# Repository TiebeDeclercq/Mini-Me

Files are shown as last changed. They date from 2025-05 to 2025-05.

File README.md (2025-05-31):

# Mini-Me

An animatronic robot that naturally mimics human movements with multiple control interfaces (UDP & Bottango)

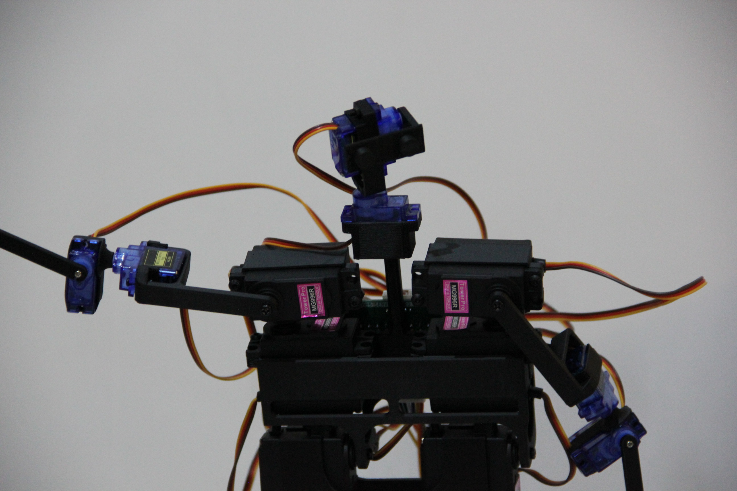
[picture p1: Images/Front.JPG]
Mini-Me


## Hardware Overview

The system uses a dual-microcontroller architecture:
- **STM32G030C8T:** Hardware control and servo management
- **ESP32-WROOM-32E-N8:** WiFi communication and external interfaces
- **19 servo motors** controlled via 2x PCA9685 PWM drivers
- **Custom PCBs** for main control and servo distribution
- **12V power supply** with buck converter and current monitoring

## Assembly Instructions

**3D Printed Parts**
The mechanical design consists of 22 different parts, all designed in Fusion 360 for the Bambu Lab P1S printer. Print all STL files from the `/Printfiles/` directory.

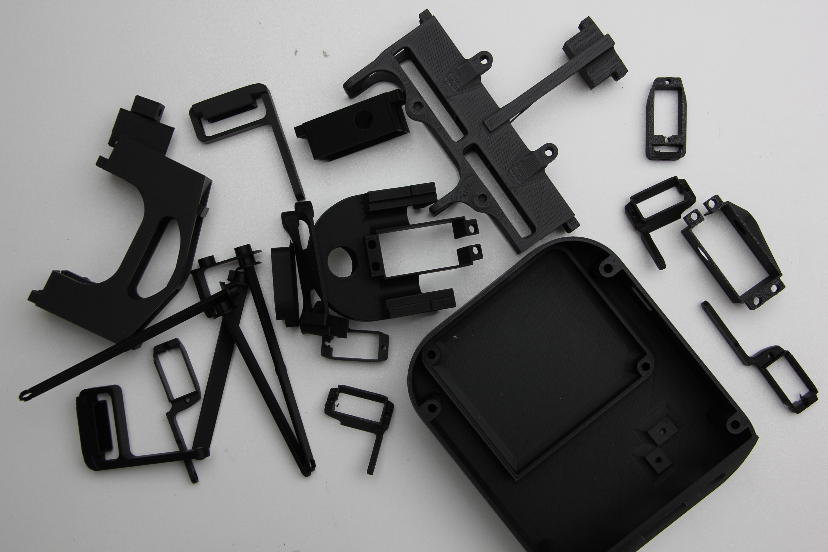
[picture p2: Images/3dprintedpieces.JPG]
3D Printed Pieces


**Magnet Integration**
During printing, pause the G-code at specified layers to insert magnets into the head, arms, and legs. This allows easy attachment of accessories and face variations.

**PCB Assembly**
1. Order PCBs using Gerber files in `/Pcb's/`
2. Solder components according to the provided BOMs
3. Main board includes ESP32, STM32, power management, and interfaces
4. Servo boards use JST connectors for secure servo connections

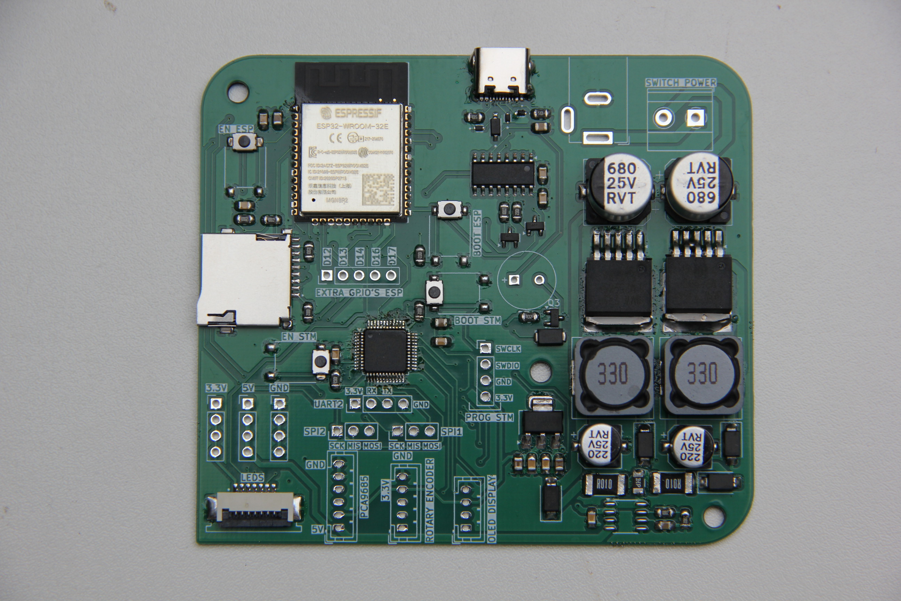
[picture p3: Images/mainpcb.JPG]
Main pcb

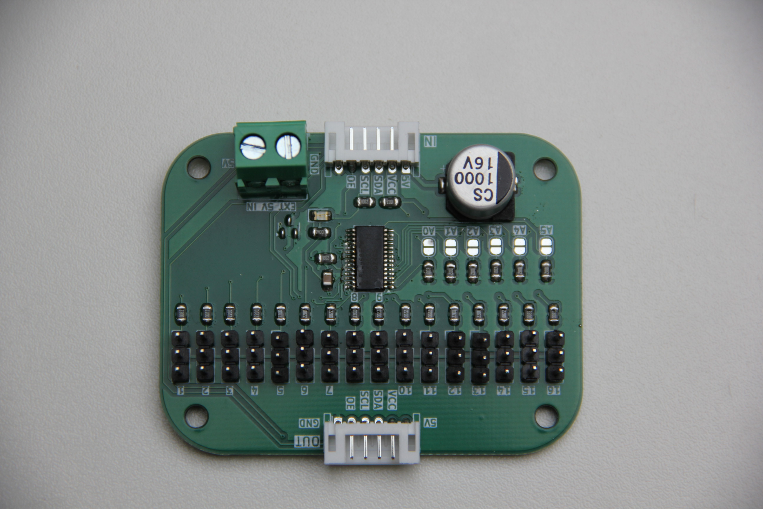
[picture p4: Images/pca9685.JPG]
Servo board pcb


**Final Assembly**
1. Install PCBs in the base/foot assembly
2. Connect servo boards via ribbon cables
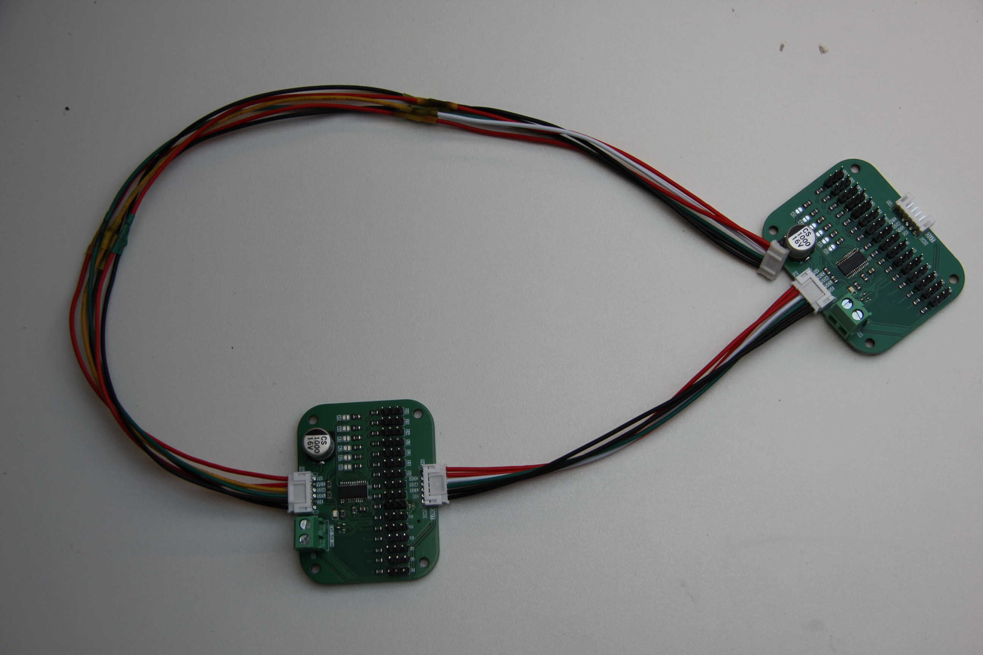
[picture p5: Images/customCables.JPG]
Custom Cables

3. Mount OLED display and rotary encoder in base
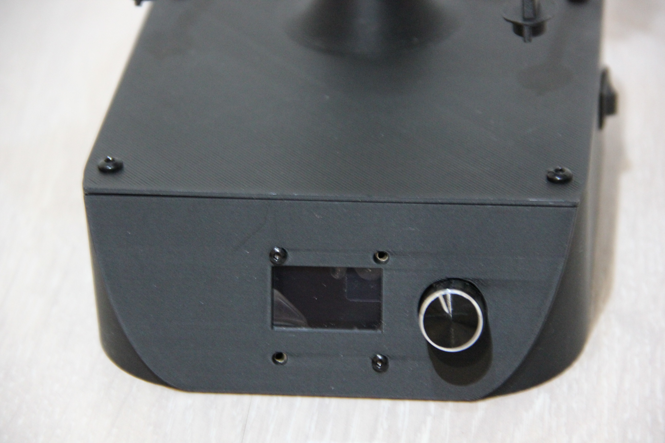
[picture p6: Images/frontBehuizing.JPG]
Base

4. Assemble skeleton parts with integrated magnets
5. Connect all servos to appropriate servo board positions

## Software

**Firmware**
- **ESP32:** Programmed with PlatformIO (C++)
- **STM32:** Programmed with STM32CubeIDE

**Control Applications**
- **Mobile App (Flutter):** Smartphone-based control interface via UDP
- **Bottango Integration:** Professional animation software compatibility

**Network Control**
The robot accepts UDP commands in JSON format:
```json
{"servo": 1, "angle": 90}
{"servos": [{"id": 1, "angle": 90}, {"id": 2, "angle": 45}]}
```

## Getting Started

1. **3D Print** all parts from `/Printfiles/`
2. **Order and assemble** PCBs using provided files and BOMs
3. **Flash firmware** from `/Firmware/Mini-Me-DevBoard/` and `/Firmware/MINI-ME-ESP32/`
4. **Install control software** of choice from `/Software/`
5. **Connect to WiFi** and start controlling via UDP or applications

**Project Report:** [Complete documentation available](docs/Mini-Me-Report.pdf)

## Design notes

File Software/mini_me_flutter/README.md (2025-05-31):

# mini_me

A new Flutter project.

## Getting Started

This project is a starting point for a Flutter application.

A few resources to get you started if this is your first Flutter project:

- [Lab: Write your first Flutter app](https://docs.flutter.dev/get-started/codelab)
- [Cookbook: Useful Flutter samples](https://docs.flutter.dev/cookbook)

For help getting started with Flutter development, view the
[online documentation](https://docs.flutter.dev/), which offers tutorials,
samples, guidance on mobile development, and a full API reference.

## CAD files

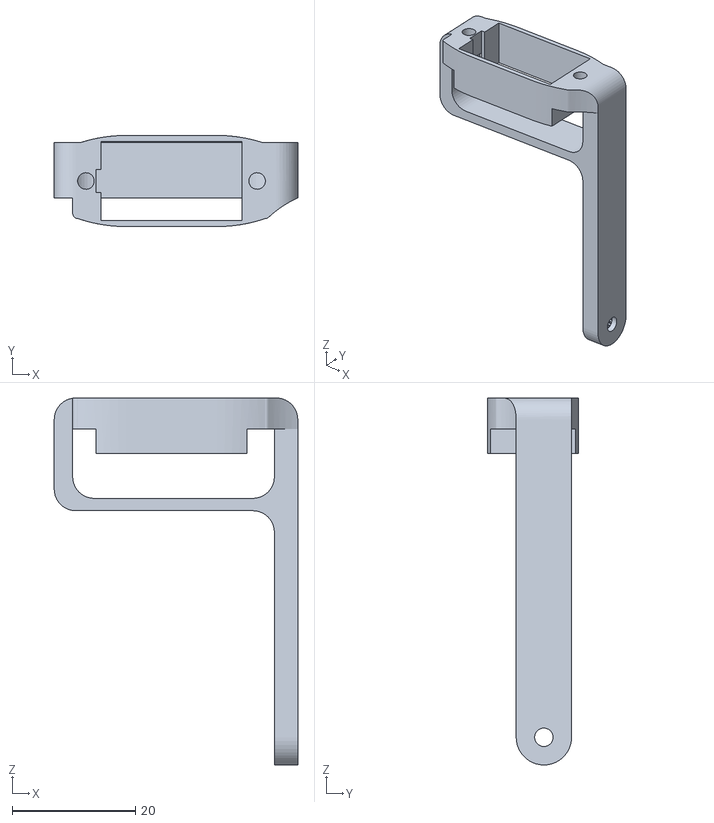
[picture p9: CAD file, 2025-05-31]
Printfiles/Lunderarm.stl
39.6 x 14.8 x 59.6

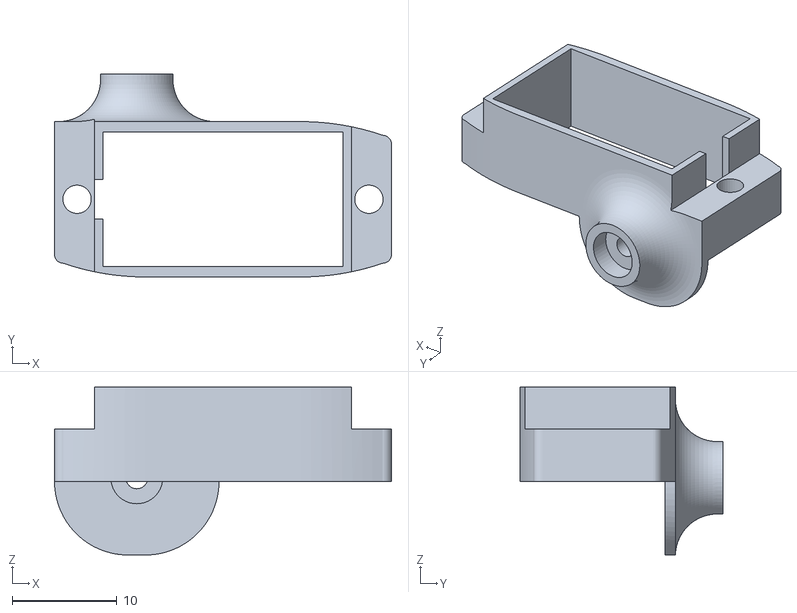
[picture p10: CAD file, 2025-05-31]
Printfiles/RupperArm.stl
32.1 x 19.3 x 16.0

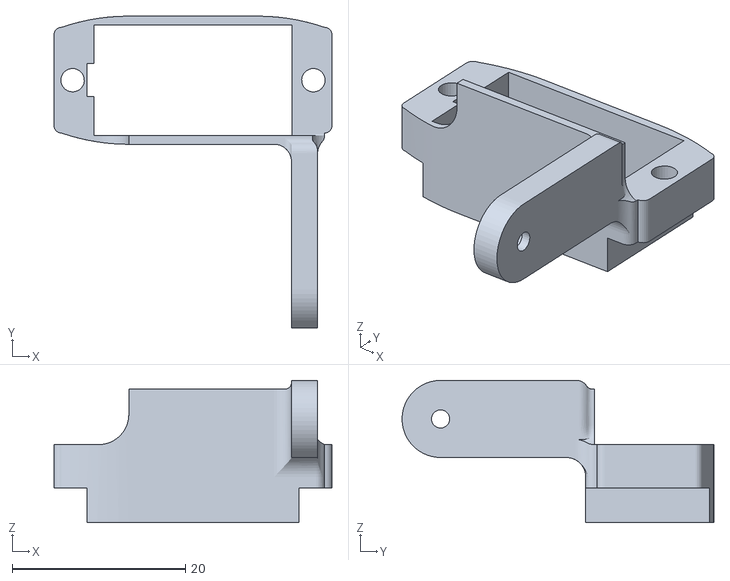
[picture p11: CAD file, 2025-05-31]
Printfiles/lUpperLeg.stl
32.1 x 36.0 x 16.4

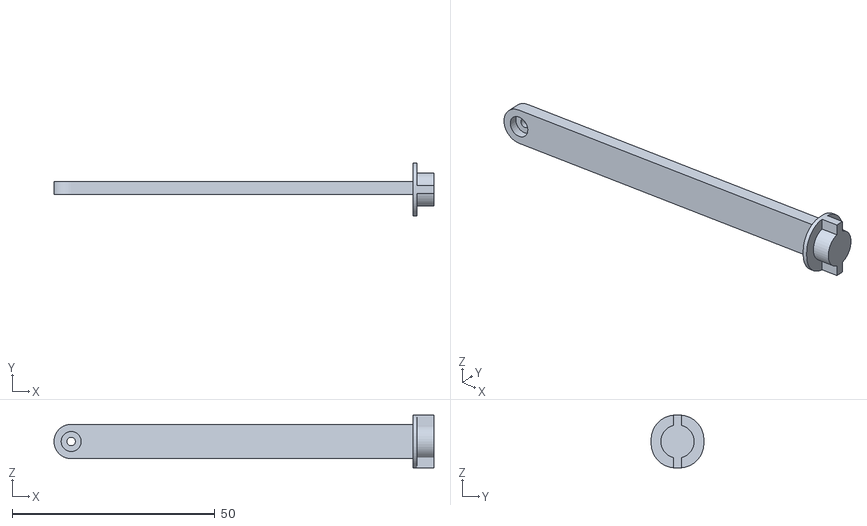
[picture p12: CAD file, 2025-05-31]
Printfiles/rLeg.stl
93.7 x 13.0 x 13.0

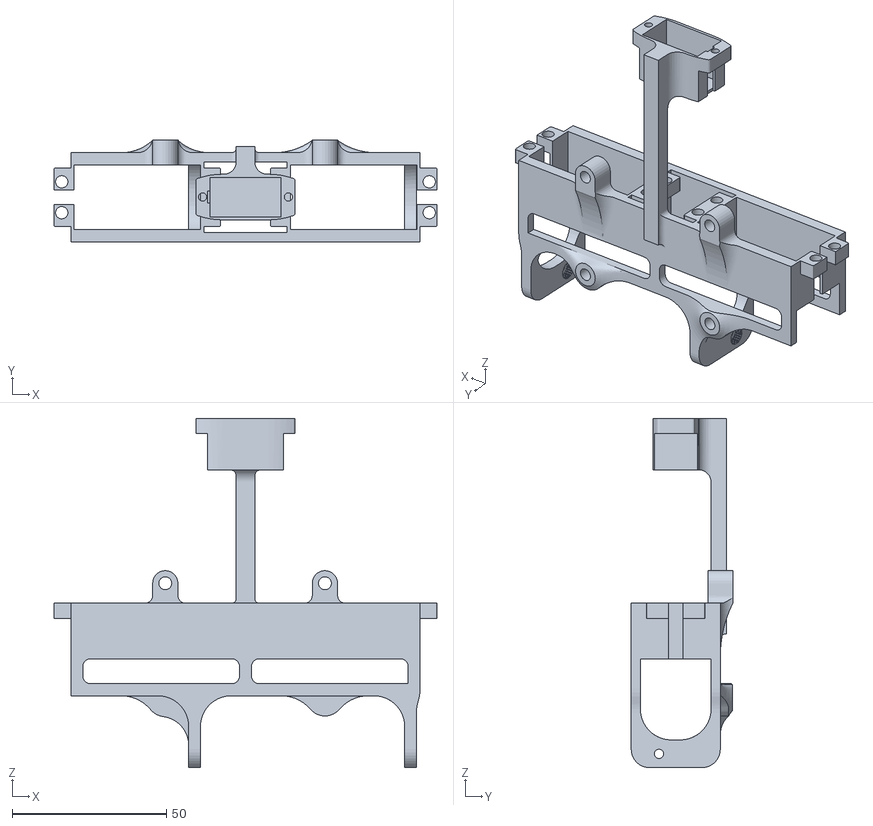
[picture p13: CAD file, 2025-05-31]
Printfiles/upperBody.stl
124.1 x 33.0 x 113.2

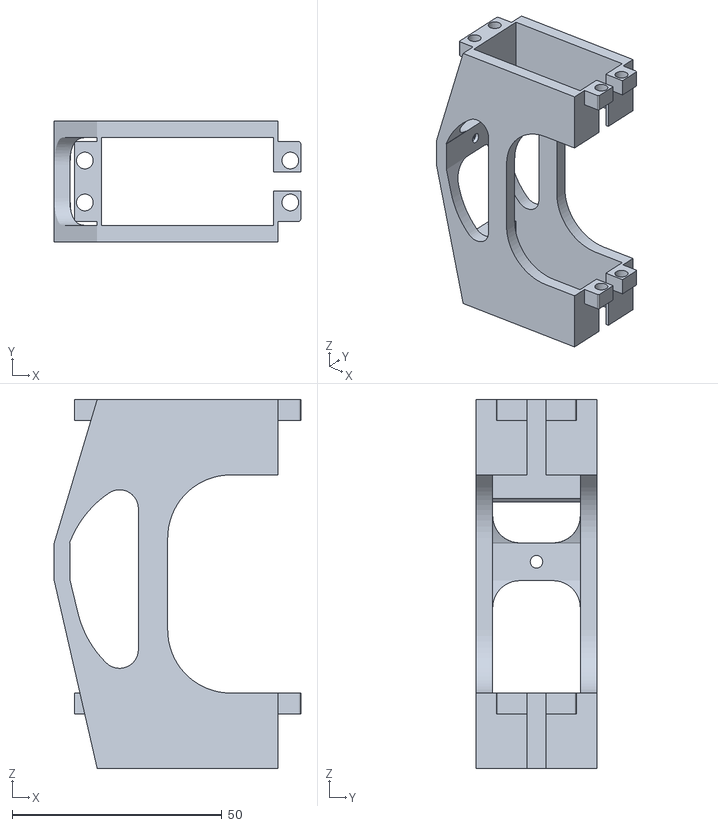
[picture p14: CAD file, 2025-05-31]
Printfiles/tummy.stl
58.8 x 28.9 x 88.0

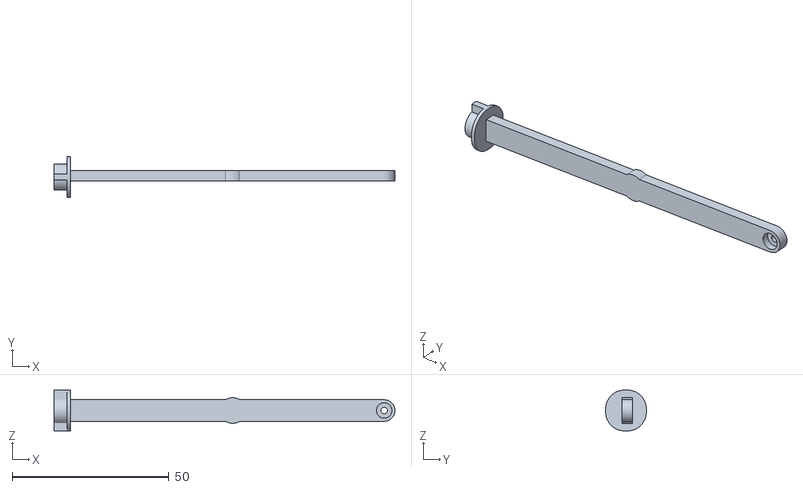
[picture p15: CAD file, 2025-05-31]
Printfiles/Larm.stl
108.6 x 13.0 x 13.0

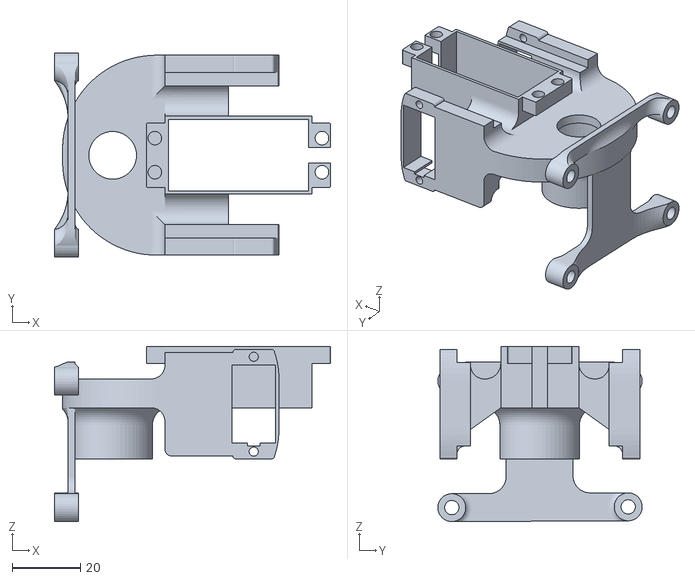
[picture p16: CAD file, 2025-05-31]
Printfiles/poop.stl
80.9 x 59.9 x 51.4

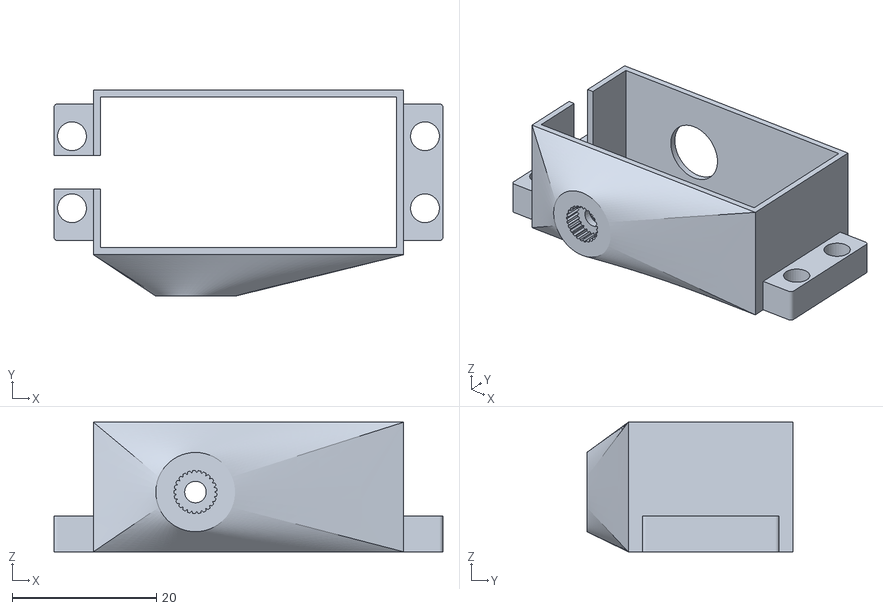
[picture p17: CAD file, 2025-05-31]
Printfiles/Relbow.stl
54.0 x 28.7 x 18.0

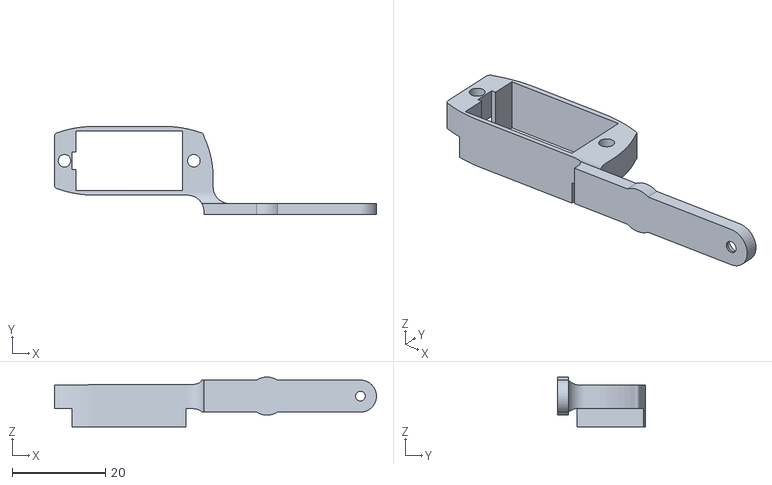
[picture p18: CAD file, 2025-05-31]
Printfiles/lMiddleLeg.stl
69.2 x 19.0 x 10.7

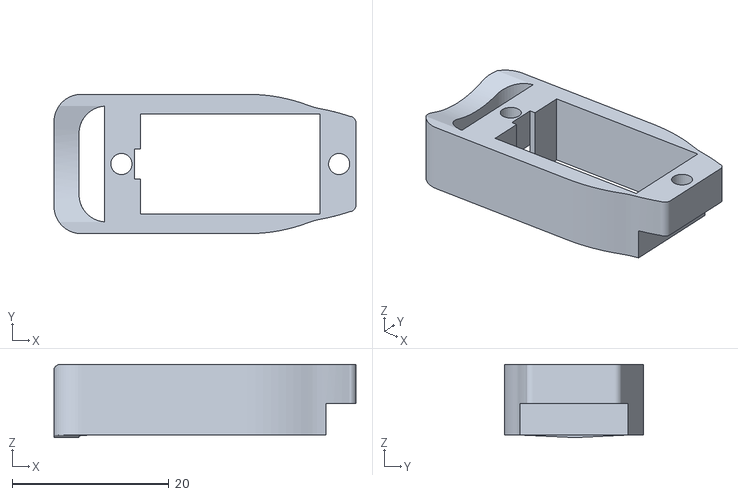
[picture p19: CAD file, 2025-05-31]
Printfiles/headY.stl
38.6 x 17.8 x 9.35

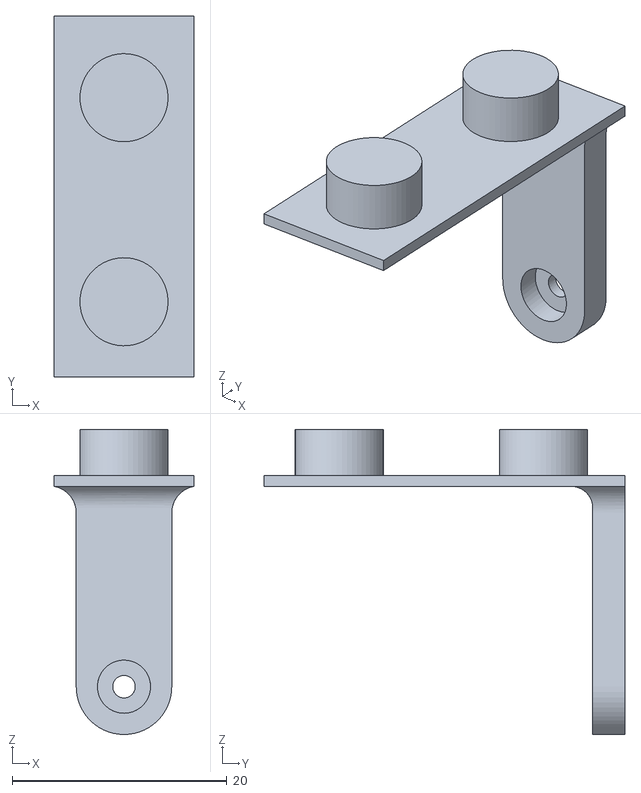
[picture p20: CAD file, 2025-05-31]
Printfiles/headX.stl
13.0 x 33.6 x 28.4

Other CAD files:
Printfiles/Lelbow.stl
Printfiles/Rlowerarm.stl
Printfiles/LYMOVEMENT.stl
Printfiles/rLowerLeg.stl
Printfiles/buttonStand.stl
Printfiles/enclosure.stl
Printfiles/lid.stl
Printfiles/rUpperLeg.stl

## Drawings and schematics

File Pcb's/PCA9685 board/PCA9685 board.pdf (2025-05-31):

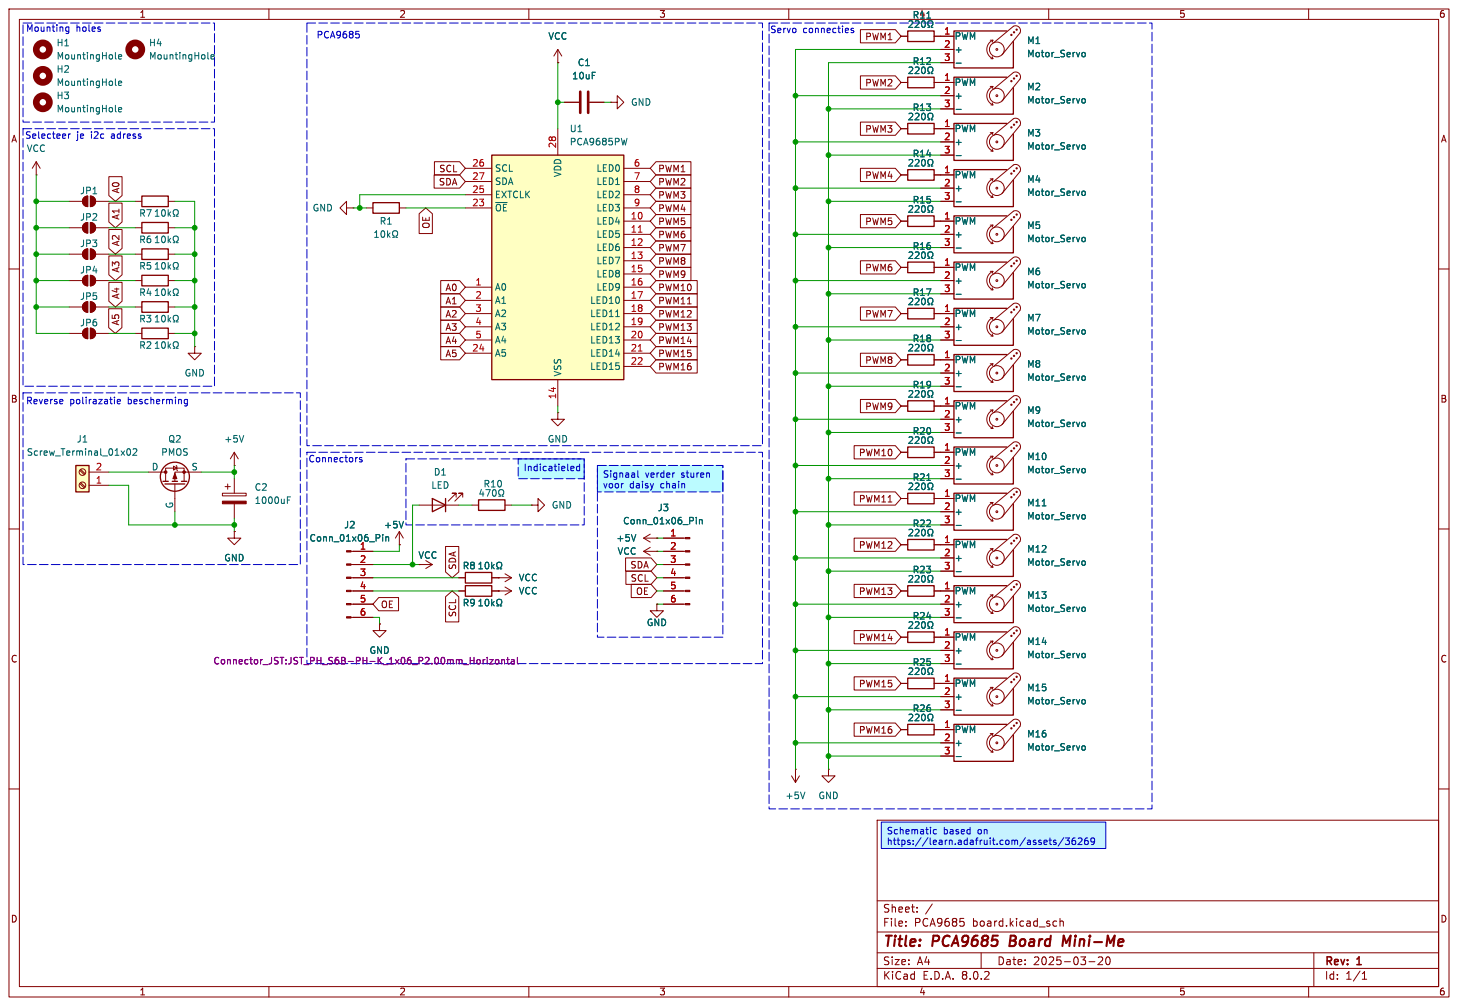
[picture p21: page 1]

https://learn.adafruit.com/assets/36269

Id: 1/1 Title: PCA9685 Board Mini-Me

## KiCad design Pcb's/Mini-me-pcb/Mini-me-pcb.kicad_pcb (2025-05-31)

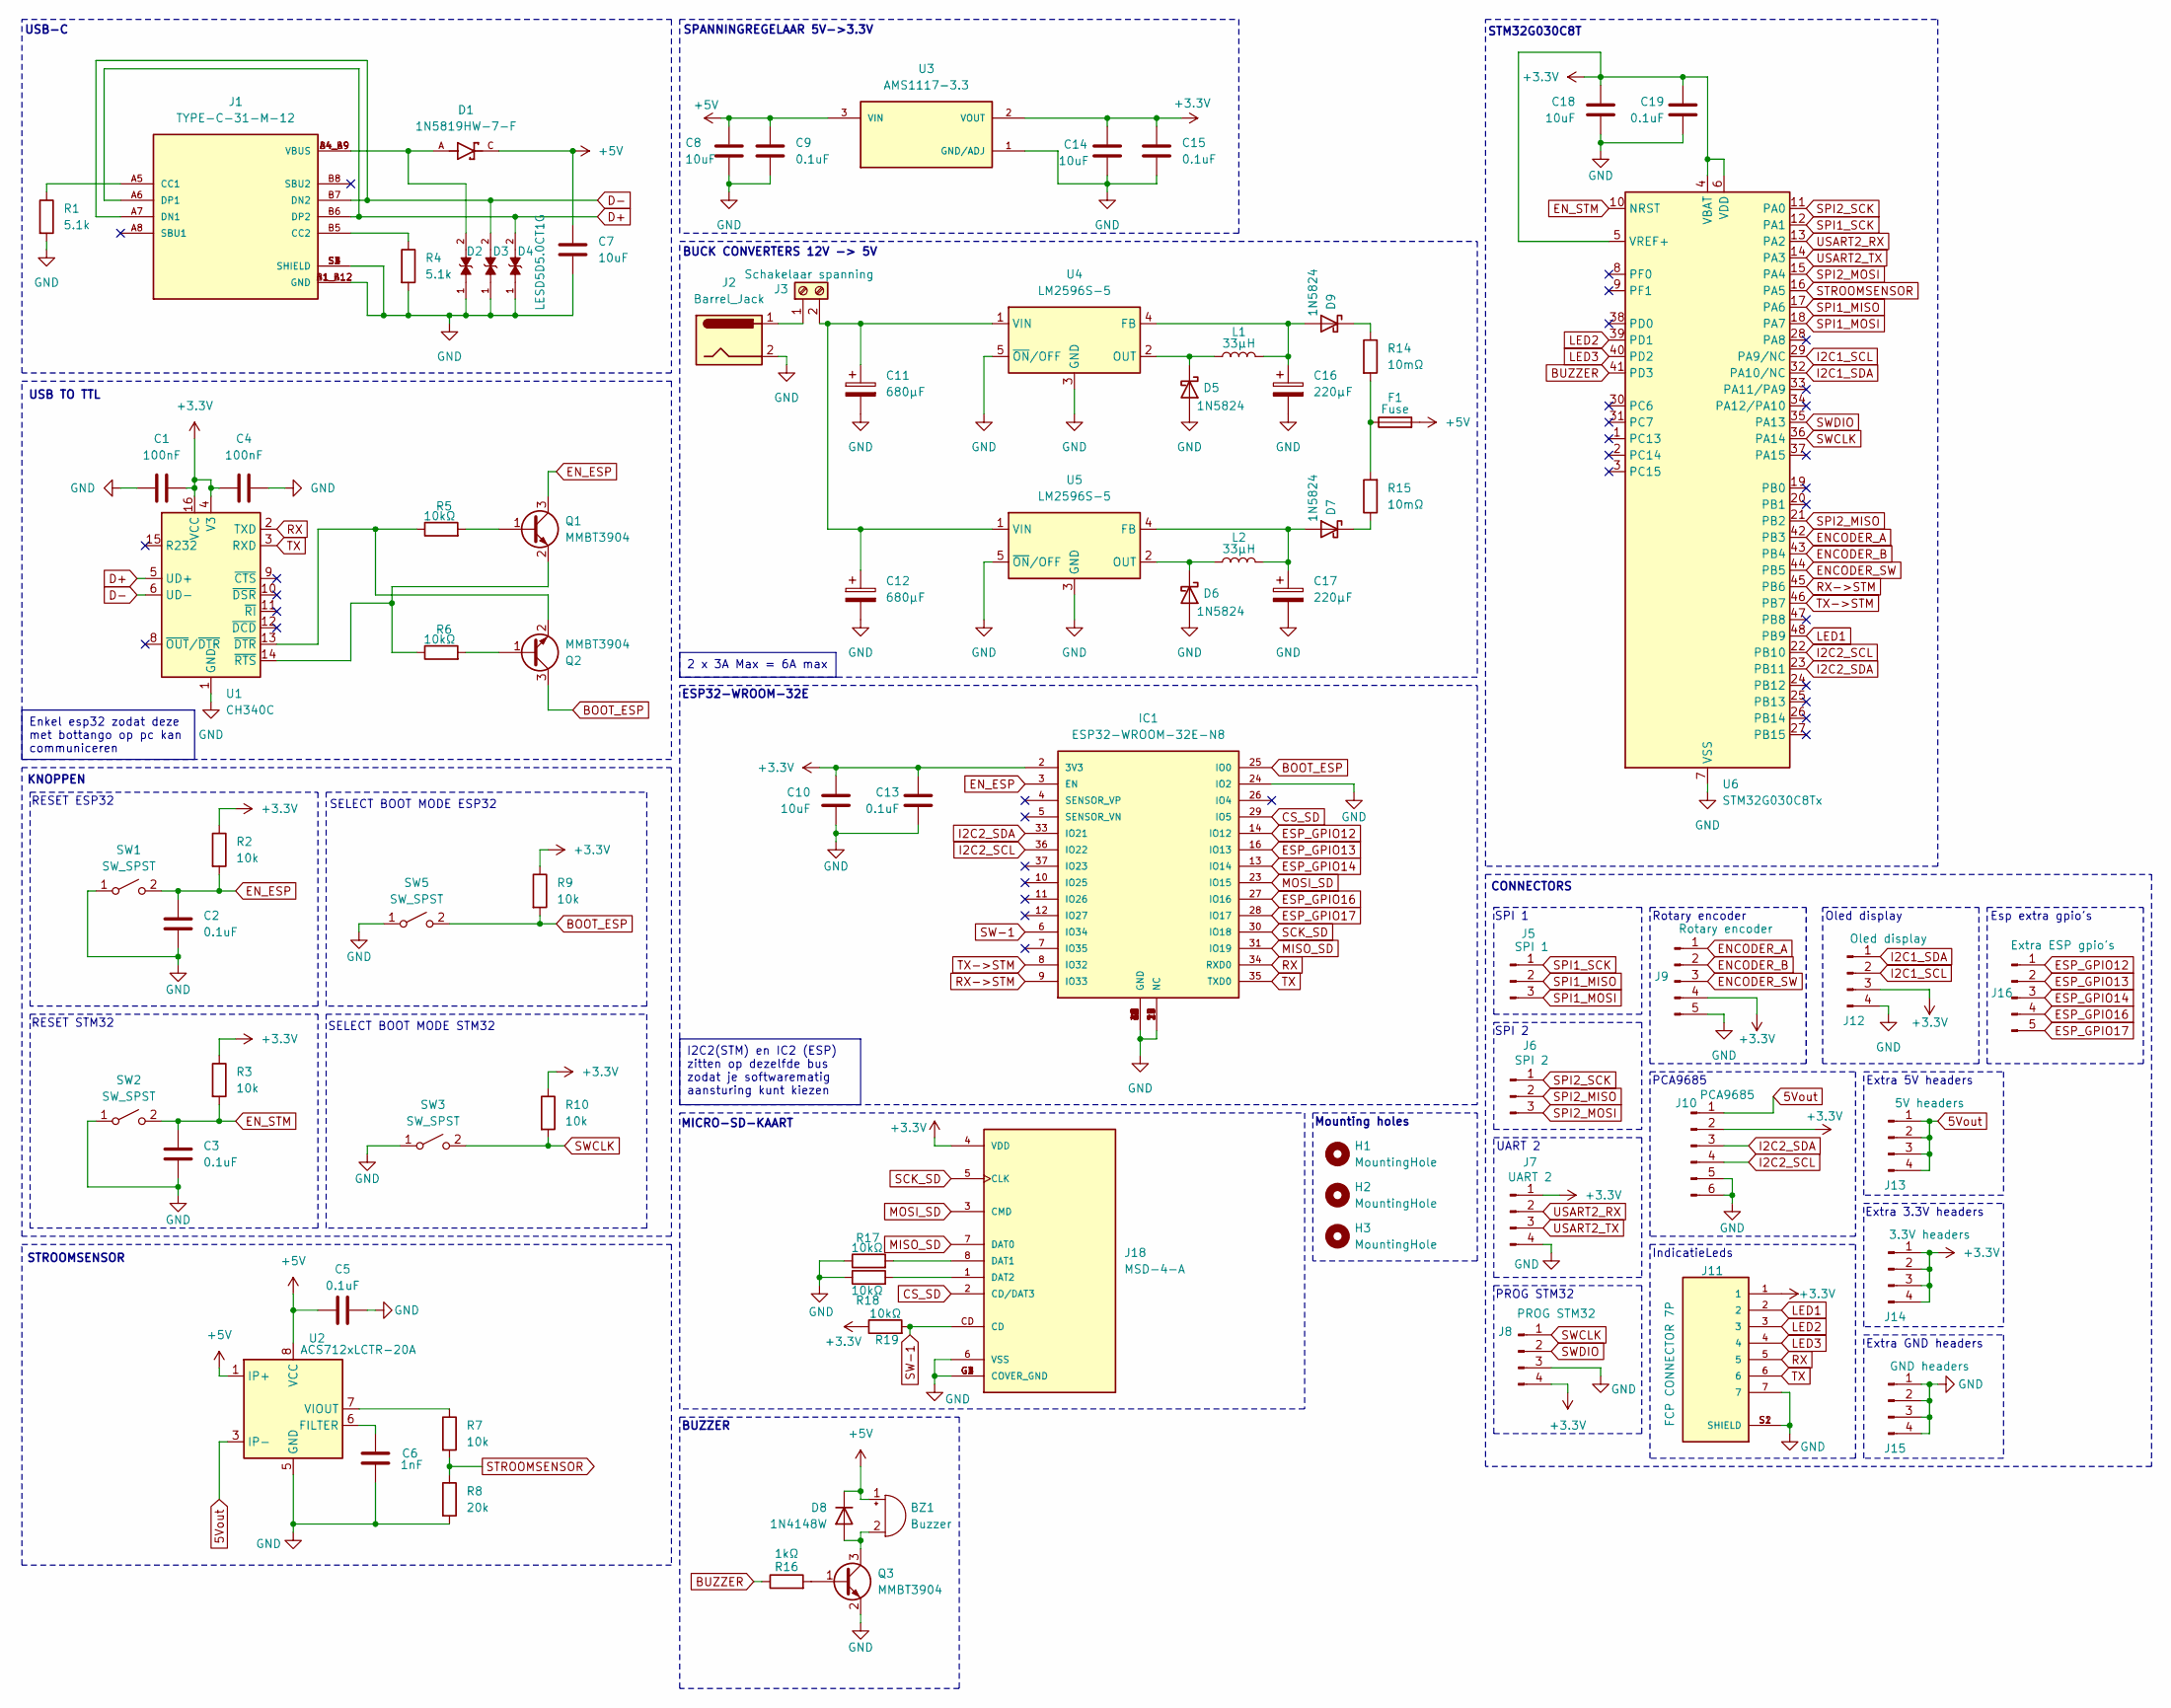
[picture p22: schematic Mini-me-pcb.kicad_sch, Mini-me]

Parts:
BZ1: Buzzer; MagneticBuzzer_PUI_AT-0927-TT-6-R
C1, C4: 100nF; C_0805_2012Metric_Pad1.18x1.45mm_HandSolder
C2, C3, C5, C9, C13, C15, C19: 0.1uF; C_0805_2012Metric_Pad1.18x1.45mm_HandSolder
C6: 1nF; C_0805_2012Metric_Pad1.18x1.45mm_HandSolder
C7, C8, C10, C14, C18: 10uF; C_0805_2012Metric_Pad1.18x1.45mm_HandSolder
C11, C12: 680µF; CP_Elec_10x10
C16, C17: 220µF; CP_Elec_6.3x7.7
D1: 1N5819HW-7-F; SOD3715X145N; PARTREV 18-2
D2, D3, D4: LESD5D5.0CT1G; TVS_LESD5D5.0CT1G; PARTREV O
D5, D6, D7, D9: 1N5824; D_SMA
D8: 1N4148W; D_SOD-123
F1: Fuse; Fuse_1206_3216Metric
H1, H2, H3: MountingHole; MountingHole_3.2mm_M3
IC1: ESP32-WROOM-32E-N8; ESP32WROOM32EN8; MOUSER_PART_NUMBER 356-ESP32WRM32E164PH
J1: TYPE-C-31-M-12; HRO_TYPE-C-31-M-12; PARTREV 2020.12.08
J2: Barrel_Jack; BarrelJack_GCT_DCJ200-10-A_Horizontal
J3: Schakelaar spanning; TerminalBlock_Phoenix_MKDS-1,5-2-5.08_1x02_P5.08mm_Horizont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
J5: SPI 1; PinHeader_1x03_P2.54mm_Vertical
J6: SPI 2; PinHeader_1x03_P2.54mm_Vertical
J7: UART 2; PinHeader_1x04_P2.54mm_Vertical
J8: PROG STM32; PinHeader_1x04_P2.54mm_Vertical
J9: Rotary encoder; JST_PH_B5B-PH-K_1x05_P2.00mm_Vertical
J10: PCA9685; JST_PH_B6B-PH-K_1x06_P2.00mm_Vertical
J11: FCP CONNECTOR 7P; FCP7P; PARTREV A4
J12: Oled display; JST_PH_B4B-PH-K_1x04_P2.00mm_Vertical
J13: 5V headers; PinHeader_1x04_P2.54mm_Vertical
J14: 3.3V headers; PinHeader_1x04_P2.54mm_Vertical
J15: GND headers; PinHeader_1x04_P2.54mm_Vertical
J16: Extra ESP gpio's; PinHeader_1x05_P2.54mm_Vertical
J18: MSD-4-A; CUI_MSD-4-A; PARTREV 1.0
L1, L2: 33µH; L_SXN_SMDRI125
Q1, Q2, Q3: MMBT3904; SOT-23
R1, R4: 5.1k; R_0805_2012Metric_Pad1.20x1.40mm_HandSolder
R2, R3, R7, R9, R10: 10k; R_0805_2012Metric_Pad1.20x1.40mm_HandSolder
R5, R6, R17, R18, R19: 10kΩ; R_0805_2012Metric_Pad1.20x1.40mm_HandSolder
R8: 20k; R_0805_2012Metric_Pad1.20x1.40mm_HandSolder
R14, R15: 10mΩ; R_2512_6332Metric
R16: 1kΩ; R_0805_2012Metric_Pad1.20x1.40mm_HandSolder
SW1, SW2, SW3, SW5: SW_SPST; SW_SPST_PTS645
U1: CH340C; SOIC-16_3.9x9.9mm_P1.27mm
U2: ACS712xLCTR-20A; SOIC-8_3.9x4.9mm_P1.27mm
U3: AMS1117-3.3; SOT-223; PARTREV N/A
U4, U5: LM2596S-5; TO-263-5_TabPin3
U6: STM32G030C8Tx; LQFP-48_7x7mm_P0.5mm

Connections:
5Vout: J10.1, J13.1, J13.2, J13.3, J13.4, U2.3 (IP-), U2.4 (IP-)
+3.3V: C1.2, C4.1, C10.1, C13.1, C14.1, C15.1, C18.1, C19.1, IC1.2 (3V3), J7.1, J8.4, J9.4, J10.2, J11.1, J12.3, J14.1, J14.2, J14.3, J14.4, J18.4 (VDD), R2.1, R3.1, R9.1, R10.1, R19.1, U1.4 (V3), U1.16 (VCC), U3.2 (VOUT), U6.4 (VBAT), U6.5 (VREF+), U6.6 (VDD)
+5V: BZ1.1 (-), C5.1, C7.1, C8.1, C9.1, D1.C, D8.1 (K), F1.2, U2.1 (IP+), U2.2 (IP+), U2.8 (VCC), U3.3 (VIN)
BOOT_ESP: IC1.25 (IO0), Q2.3 (C), R9.2, SW5.2 (B)
BUZZER: R16.1, U6.41 (PD3)
CS_SD: IC1.29 (IO5), J18.2 (CD/DAT3)
D+: D4.2, J1.A6 (DP1), J1.B6 (DP2), U1.5 (UD+)
D-: D3.2, J1.A7 (DN1), J1.B7 (DN2), U1.6 (UD-)
ENCODER_A: J9.1, U6.42 (PB3)
ENCODER_B: J9.2, U6.43 (PB4)
ENCODER_SW: J9.3, U6.44 (PB5)
EN_ESP: C2.1, IC1.3 (EN), Q1.3 (C), R2.2, SW1.2 (B)
EN_STM: C3.1, R3.2, SW2.2 (B), U6.10 (NRST)
ESP_GPIO12: IC1.14 (IO12), J16.1
ESP_GPIO13: IC1.16 (IO13), J16.2
ESP_GPIO14: IC1.13 (IO14), J16.3
ESP_GPIO16: IC1.27 (IO16), J16.4
ESP_GPIO17: IC1.28 (IO17), J16.5
GND: C1.1, C2.2, C3.2, C4.2, C5.2, C6.2, C7.2, C8.2, C9.2, C10.2, C11.2, C12.2, C13.2, C14.2, C15.2, C16.2, C17.2, C18.2, C19.2, D2.1, D3.1, D4.1, D5.2 (A), D6.2 (A), IC1.1 (GND), IC1.15 (GND), IC1.17 (NC), IC1.18 (NC), IC1.19 (NC), IC1.20 (NC), IC1.21 (NC), IC1.22 (NC), IC1.24 (IO2), IC1.32 (NC), IC1.38 (GND), IC1.39 (GND), IC1.40 (GND), IC1.41 (GND), IC1.42 (GND), IC1.43 (GND), IC1.44 (GND), IC1.45 (GND), IC1.46 (GND), IC1.47 (GND), J1.A1_B12 (GND), J1.B1_A12 (GND), J1.S1 (SHIELD), J1.S2 (SHIELD), J1.S3 (SHIELD), J1.S4 (SHIELD), J2.2, J7.4, J8.3, J9.5, J10.5, J10.6, J11.7, J11.S1 (SHIELD), J11.S2 (SHIELD), J12.4, J15.1, J15.2, J15.3, J15.4, J18.6 (VSS), J18.G1 (COVER_GND), J18.G2 (COVER_GND), J18.G3 (COVER_GND), J18.G4 (COVER_GND), Q3.2 (E), R1.2, R4.2, R8.2, R17.1, R18.1, SW1.1 (A), SW2.1 (A), SW3.1 (A), SW5.1 (A), U1.1 (GND), U2.5 (GND), U3.1 (GND/ADJ), U4.3 (GND), U4.5 (~ON/OFF), U5.3 (GND), U5.5 (~ON/OFF), U6.7 (VSS)
I2C1_SCL: J12.2, U6.29 (PA9/NC)
I2C1_SDA: J12.1, U6.32 (PA10/NC)
I2C2_SCL: IC1.36 (IO22), J10.4, U6.22 (PB10)
I2C2_SDA: IC1.33 (IO21), J10.3, U6.23 (PB11)
LED1: J11.2, U6.48 (PB9)
LED2: J11.3, U6.39 (PD1)
LED3: J11.4, U6.40 (PD2)
MISO_SD: IC1.31 (IO19), J18.7 (DAT0)
MOSI_SD: IC1.23 (IO15), J18.3 (CMD)
unnamed: BZ1.2 (+), D8.2 (A), Q3.3 (C)
unnamed: D1.A, D2.2, J1.A4_B9 (VBUS), J1.B4_A9 (VBUS)
unnamed: D5.1 (K), L1.1, U4.2 (OUT)
unnamed: D6.1 (K), L2.1, U5.2 (OUT)
unnamed: C17.1, D7.2 (A), L2.2, U5.4 (FB)
unnamed: D7.1 (K), R15.1
unnamed: C16.1, D9.2 (A), L1.2, U4.4 (FB)
unnamed: D9.1 (K), R14.1
unnamed: F1.1, R14.2, R15.2
unnamed: J1.A5 (CC1), R1.1
unnamed: J1.B5 (CC2), R4.1
unnamed: J2.1, J3.1
unnamed: C11.1, C12.1, J3.2, U4.1 (VIN), U5.1 (VIN)
unnamed: J18.8 (DAT1), R17.2
unnamed: J18.1 (DAT2), R18.2
unnamed: Q1.1 (B), R5.2
unnamed: Q1.2 (E), R6.1, U1.14 (~RTS)
unnamed: Q2.1 (B), R6.2
unnamed: Q2.2 (E), R5.1, U1.13 (~DTR)
unnamed: Q3.1 (B), R16.2
unnamed: C6.1, U2.6 (FILTER)
unnamed: R7.1, U2.7 (VIOUT)
RX: IC1.34 (RXD0), J11.5, U1.2 (TXD)
RX->STM: IC1.9 (IO33), U6.45 (PB6)
SCK_SD: IC1.30 (IO18), J18.5 (CLK)
SPI1_MISO: J5.2, U6.17 (PA6)
SPI1_MOSI: J5.3, U6.18 (PA7)
SPI1_SCK: J5.1, U6.12 (PA1)
SPI2_MISO: J6.2, U6.21 (PB2)
SPI2_MOSI: J6.3, U6.15 (PA4)
SPI2_SCK: J6.1, U6.11 (PA0)
STROOMSENSOR: R7.2, R8.1, U6.16 (PA5)
SW-1: IC1.6 (IO34), J18.CD, R19.2
SWCLK: J8.1, R10.2, SW3.2 (B), U6.36 (PA14)
SWDIO: J8.2, U6.35 (PA13)
TX: IC1.35 (TXD0), J11.6, U1.3 (RXD)
TX->STM: IC1.8 (IO32), U6.46 (PB7)
USART2_RX: J7.2, U6.13 (PA2)
USART2_TX: J7.3, U6.14 (PA3)

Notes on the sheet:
I2C2(STM) en IC2 (ESP) zitten op dezelfde bus zodat je softwarematig aansturing kunt kiezen
Enkel esp32 zodat deze met bottango op pc kan communiceren
2 x 3A Max = 6A max
STM32G030C8T
SELECT BOOT MODE ESP32
SPI 2
BUZZER
Extra 3.3V headers
Oled display
Mounting holes
STROOMSENSOR
Extra GND headers
MICRO-SD-KAART
USB-C
Esp extra gpio's
SPANNINGREGELAAR 5V->3.3V
Rotary encoder
IndicatieLeds
UART 2
Extra 5V headers
SELECT BOOT MODE STM32
KNOPPEN
SPI 1
PCA9685
RESET STM32
RESET ESP32
CONNECTORS
USB TO TTL
BUCK CONVERTERS 12V -> 5V
ESP32-WROOM-32E
PROG STM32

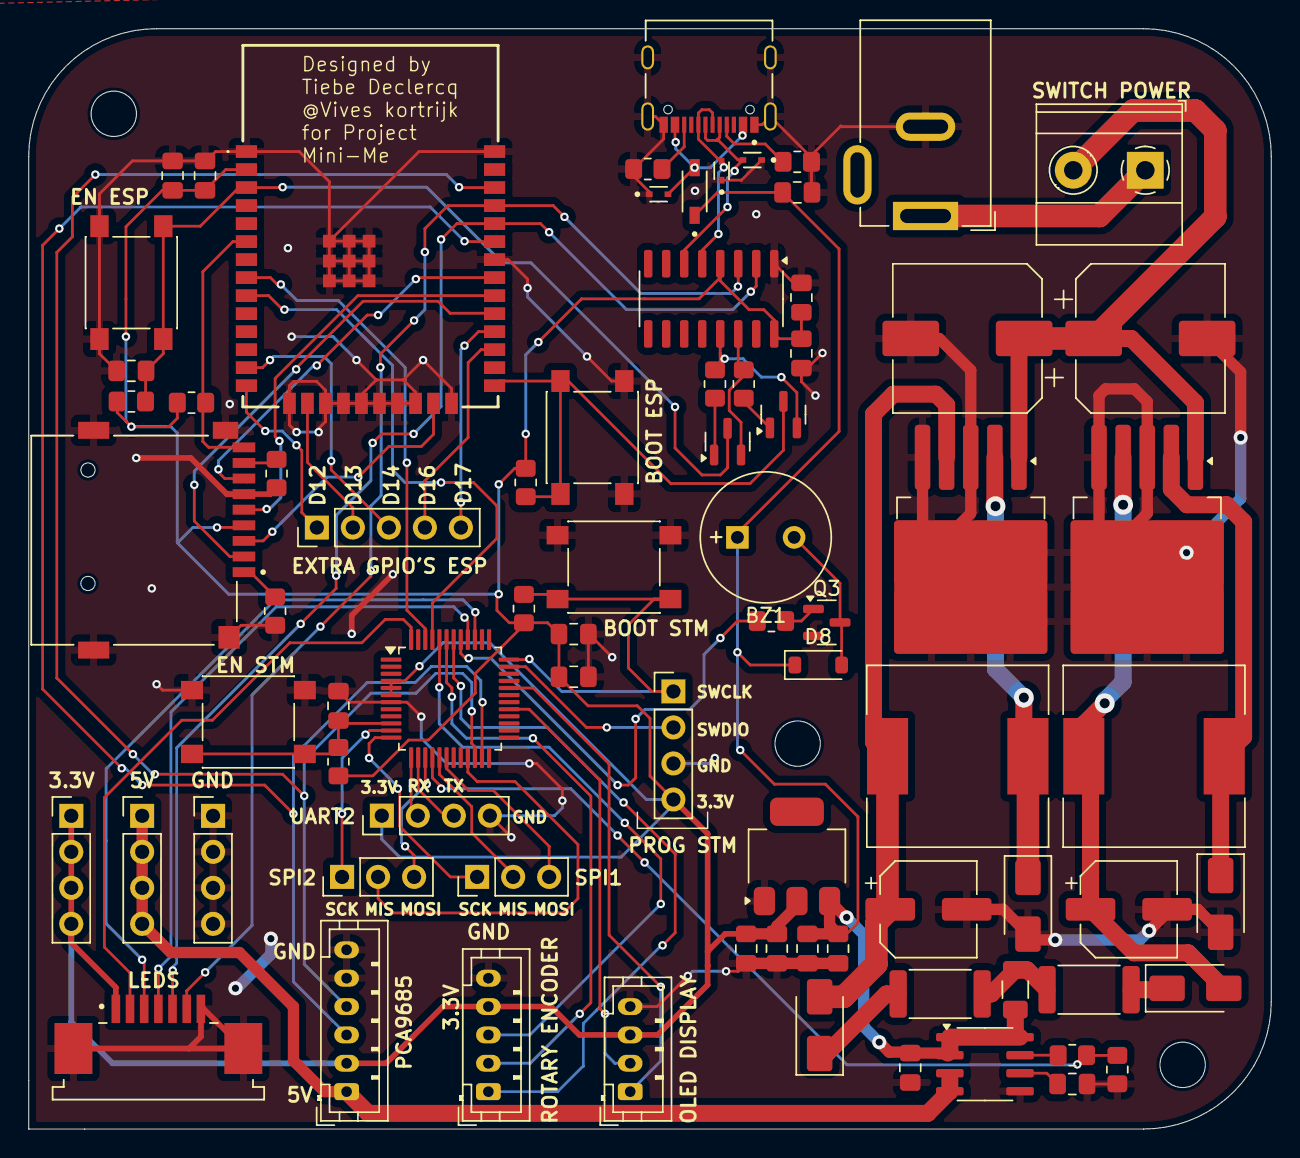
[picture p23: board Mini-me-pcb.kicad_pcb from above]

Board: 2 copper layers, 87.6 x 77.6 mm, 81 parts (0 on the bottom side), 67 nets.

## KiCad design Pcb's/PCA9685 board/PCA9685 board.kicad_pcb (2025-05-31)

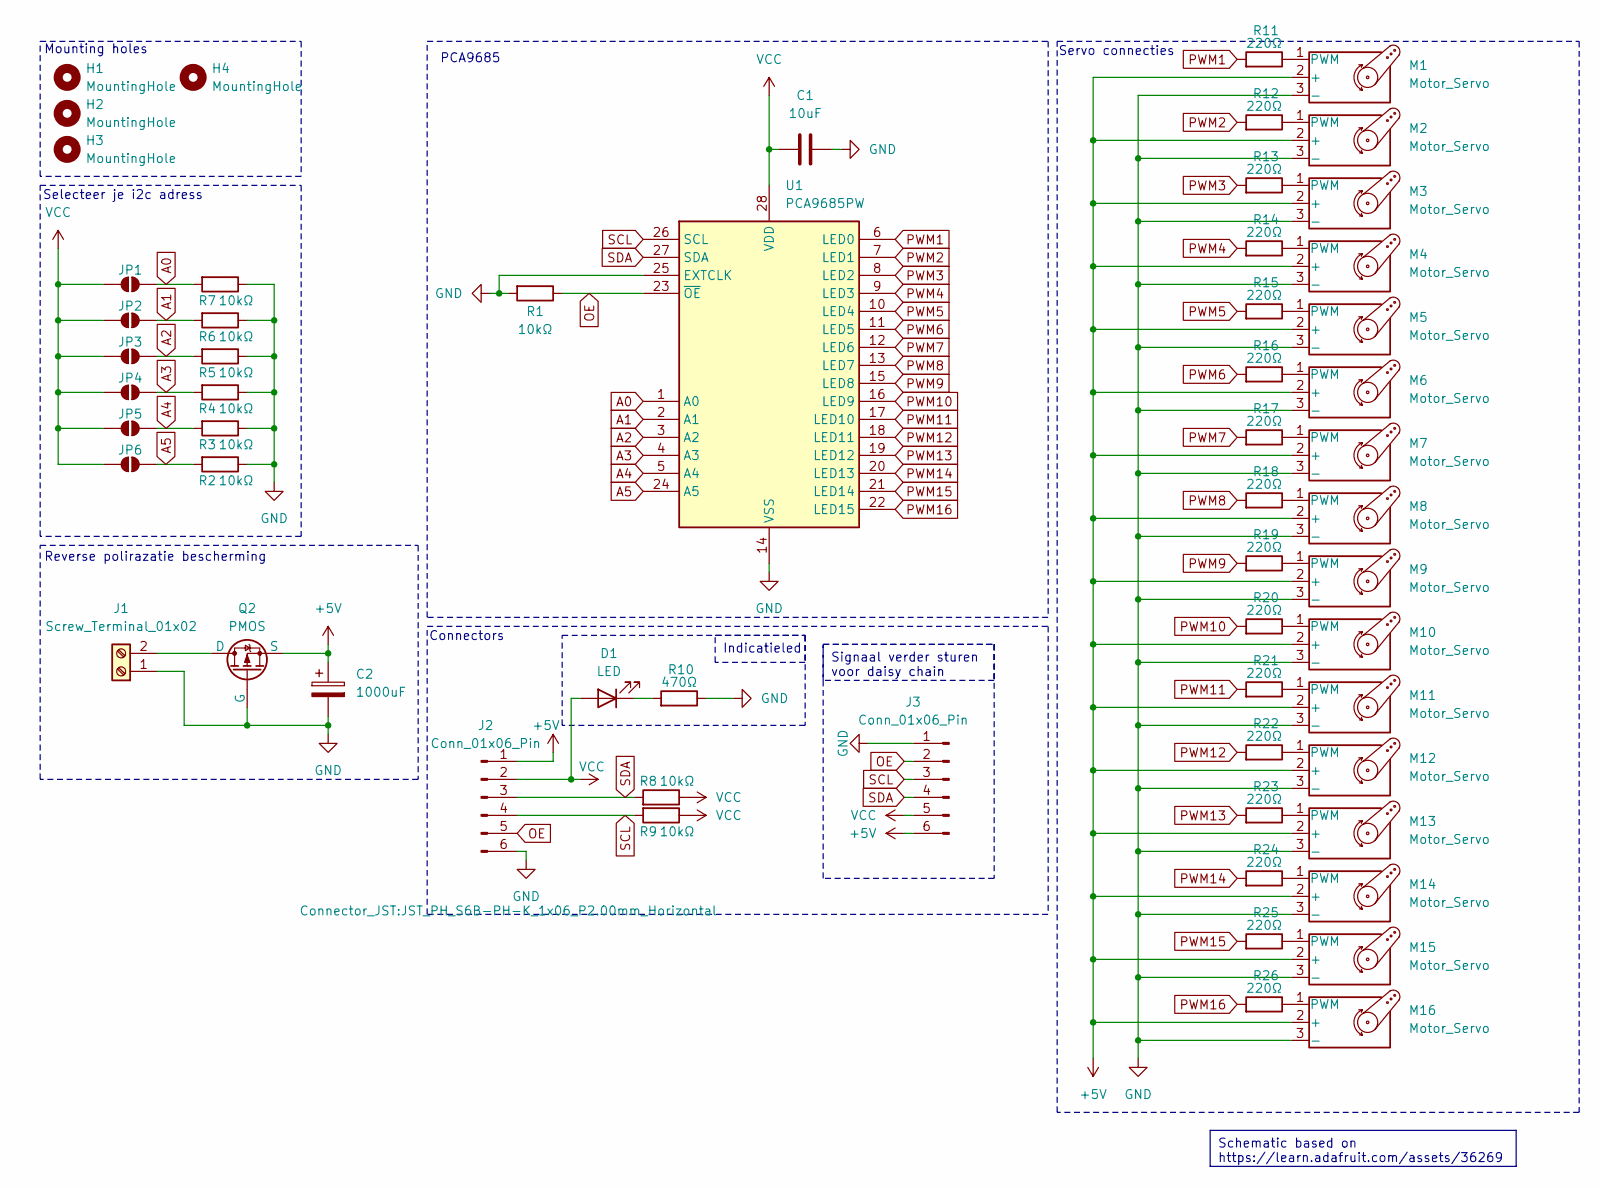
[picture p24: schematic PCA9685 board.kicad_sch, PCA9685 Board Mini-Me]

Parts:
C1: 10uF; C_0805_2012Metric_Pad1.18x1.45mm_HandSolder
C2: 1000uF; CP_Elec_8x10.5
D1: LED; LED_0805_2012Metric_Pad1.15x1.40mm_HandSolder
H1, H2, H3, H4: MountingHole; MountingHole_3.2mm_M3
J1: Screw_Terminal_01x02; TerminalBlock_Phoenix_MKDS-1,5-2-5.08_1x02_P5.08mm_Horizont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
J2, J3: Conn_01x06_Pin; JST_PH_S6B-PH-K_1x06_P2.00mm_Horizontal
JP1, JP2, JP3, JP4, JP5, JP6: SolderJumper_2_Open; SolderJumper-2_P1.3mm_Open_RoundedPad1.0x1.5mm
M1, M2, M3, M4, M5, M6, M7, M8, M9, M10, M11, M12, M13, M14, M15, M16: Motor_Servo; PinHeader_1x03_P2.54mm_Vertical
Q2: PMOS; SOT-23
R1, R2, R3, R4, R5, R6, R7, R8, R9: 10kΩ; R_0805_2012Metric_Pad1.20x1.40mm_HandSolder
R10: 470Ω; R_0805_2012Metric_Pad1.20x1.40mm_HandSolder
R11, R12, R13, R14, R15, R16, R17, R18, R19, R20, R21, R22, R23, R24, R25, R26: 220Ω; R_0805_2012Metric_Pad1.20x1.40mm_HandSolder
U1: PCA9685PW; TSSOP-28_4.4x9.7mm_P0.65mm

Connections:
+5V: C2.1, J2.1, J3.6, M1.2 (+), M2.2 (+), M3.2 (+), M4.2 (+), M5.2 (+), M6.2 (+), M7.2 (+), M8.2 (+), M9.2 (+), M10.2 (+), M11.2 (+), M12.2 (+), M13.2 (+), M14.2 (+), M15.2 (+), M16.2 (+), Q2.3 (S)
A0: JP1.2 (B), R7.2, U1.1 (A0)
A1: JP2.2 (B), R6.2, U1.2 (A1)
A2: JP3.2 (B), R5.2, U1.3 (A2)
A3: JP4.2 (B), R4.2, U1.4 (A3)
A4: JP5.2 (B), R3.2, U1.5 (A4)
A5: JP6.2 (B), R2.2, U1.24 (A5)
GND: C1.2, C2.2, J1.1, J2.6, J3.1, M1.3 (-), M2.3 (-), M3.3 (-), M4.3 (-), M5.3 (-), M6.3 (-), M7.3 (-), M8.3 (-), M9.3 (-), M10.3 (-), M11.3 (-), M12.3 (-), M13.3 (-), M14.3 (-), M15.3 (-), M16.3 (-), Q2.2 (G), R1.2, R2.1, R3.1, R4.1, R5.1, R6.1, R7.1, R10.1, U1.14 (VSS), U1.25 (EXTCLK)
unnamed: D1.1 (K), R10.2
unnamed: J1.2, Q2.1 (D)
unnamed: M1.1 (PWM), R11.1
unnamed: M2.1 (PWM), R12.1
unnamed: M3.1 (PWM), R13.1
unnamed: M4.1 (PWM), R14.1
unnamed: M5.1 (PWM), R15.1
unnamed: M6.1 (PWM), R16.1
unnamed: M7.1 (PWM), R17.1
unnamed: M8.1 (PWM), R18.1
unnamed: M9.1 (PWM), R19.1
unnamed: M10.1 (PWM), R20.1
unnamed: M11.1 (PWM), R21.1
unnamed: M12.1 (PWM), R22.1
unnamed: M13.1 (PWM), R23.1
unnamed: M14.1 (PWM), R24.1
unnamed: M15.1 (PWM), R25.1
unnamed: M16.1 (PWM), R26.1
OE: J2.5, J3.2, R1.1, U1.23 (~OE)
PWM1: R11.2, U1.6 (LED0)
PWM2: R12.2, U1.7 (LED1)
PWM3: R13.2, U1.8 (LED2)
PWM4: R14.2, U1.9 (LED3)
PWM5: R15.2, U1.10 (LED4)
PWM6: R16.2, U1.11 (LED5)
PWM7: R17.2, U1.12 (LED6)
PWM8: R18.2, U1.13 (LED7)
PWM9: R19.2, U1.15 (LED8)
PWM10: R20.2, U1.16 (LED9)
PWM11: R21.2, U1.17 (LED10)
PWM12: R22.2, U1.18 (LED11)
PWM13: R23.2, U1.19 (LED12)
PWM14: R24.2, U1.20 (LED13)
PWM15: R25.2, U1.21 (LED14)
PWM16: R26.2, U1.22 (LED15)
SCL: J2.4, J3.3, R9.2, U1.26 (SCL)
SDA: J2.3, J3.4, R8.2, U1.27 (SDA)
VCC: C1.1, D1.2 (A), J2.2, J3.5, JP1.1 (A), JP2.1 (A), JP3.1 (A), JP4.1 (A), JP5.1 (A), JP6.1 (A), R8.1, R9.1, U1.28 (VDD)

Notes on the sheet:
Schematic based on https://learn.adafruit.com/assets/36269
Indicatieled
Signaal verder sturen voor daisy chain
Mounting holes
Connectors
PCA9685
Reverse polirazatie bescherming
Selecteer je i2c adress
Servo connecties

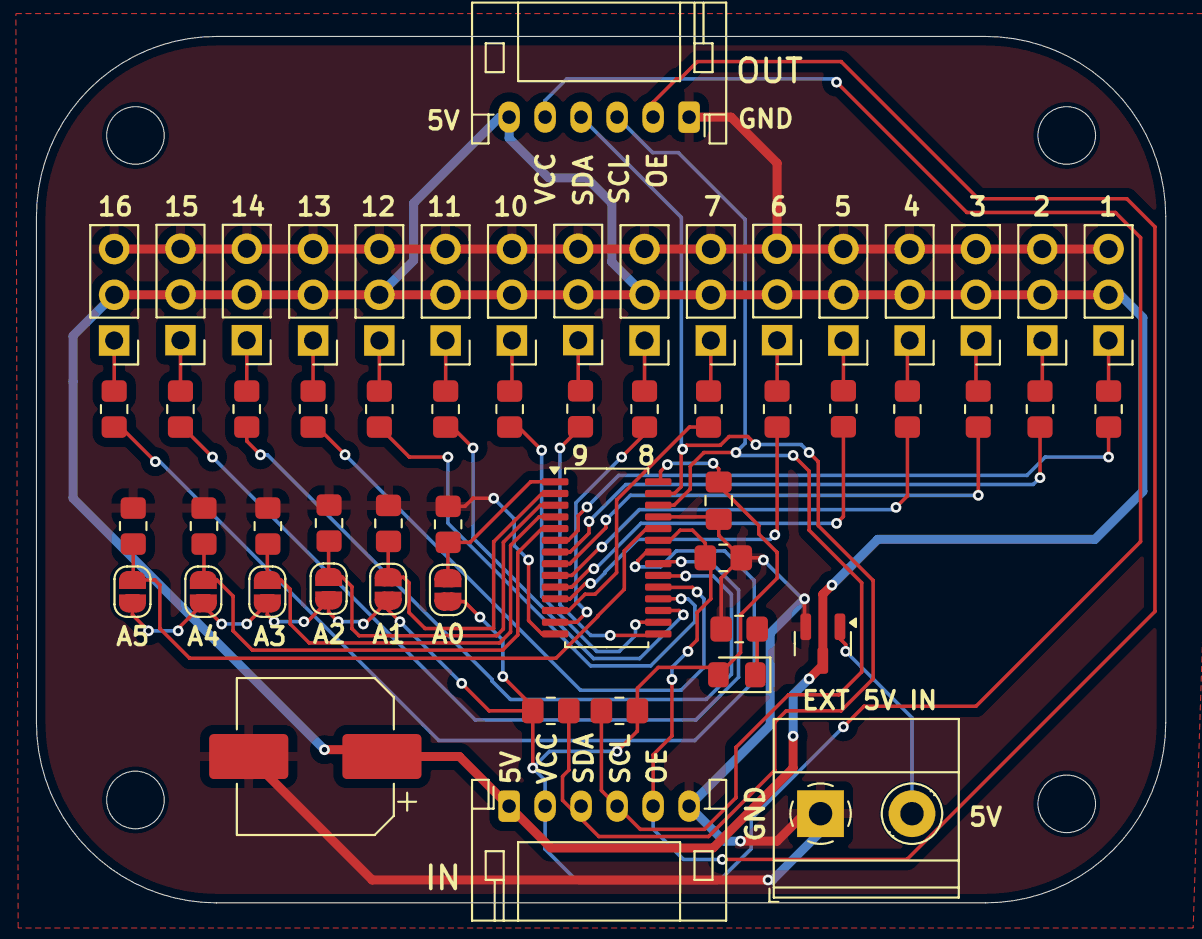
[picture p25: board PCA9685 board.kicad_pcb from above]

Board: 2 copper layers, 62.7 x 48.1 mm, 60 parts (0 on the bottom side), 46 nets.

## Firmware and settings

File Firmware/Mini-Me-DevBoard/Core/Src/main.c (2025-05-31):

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
/* Includes ------------------------------------------------------------------*/
#include "main.h"

/* USER CODE BEGIN Includes */
#include "ssd1306.h"
#include "ssd1306_fonts.h"
#include "display.h"
#include "rotary.h"
#include "pca9685.h"
#include "jsmn.h"
#include <string.h>
#include <stdlib.h>
/* USER CODE END Includes */

/* USER CODE BEGIN PD */
#define JSON_BUFFER_SIZE 1024 // Buffer for JSON data
/* USER CODE END PD */

I2C_HandleTypeDef hi2c1;

UART_HandleTypeDef huart1;
UART_HandleTypeDef huart2;

/* USER CODE BEGIN PV */
uint8_t rx_buffer[JSON_BUFFER_SIZE];
uint8_t rx_data;  // Single byte for receiving
uint16_t rx_index = 0;
volatile uint8_t message_received = 0;
/* USER CODE END PV */

void SystemClock_Config(void);
static void MX_GPIO_Init(void);
static void MX_I2C1_Init(void);
static void MX_USART1_UART_Init(void);
static void MX_USART2_UART_Init(void);
/* USER CODE BEGIN PFP */
static int jsoneq(const char *json, jsmntok_t *tok, const char *s);
static int extract_int(const char *json, jsmntok_t *tok);
void ProcessServoCommand(const char *json_string);
void send_uart_message(const char* message);
/* USER CODE END PFP */

/* USER CODE BEGIN 0 */
// Helper function to check if JSON token matches a string
static int jsoneq(const char *json, jsmntok_t *tok, const char *s) {
    if (tok->type == JSMN_STRING &&
        (int)strlen(s) == tok->end - tok->start &&
        strncmp(json + tok->start, s, (size_t)(tok->end - tok->start)) == 0) {
        return 0;
    }
    return -1;
}

// Helper function to extract integer value from token
static int extract_int(const char *json, jsmntok_t *tok) {
    char value[8] = {0}; // Buffer for number conversion
    size_t len = (size_t)(tok->end - tok->start);
    if (len >= sizeof(value)) len = sizeof(value) - 1;
    strncpy(value, json + tok->start, len);
    return atoi(value);
}

void ProcessServoCommand(const char *json_string) {
    jsmn_parser parser;
    jsmntok_t tokens[64]; // Adjust size based on your needs

    jsmn_init(&parser);
    int r = jsmn_parse(&parser, json_string, strlen(json_string), tokens, 64);

    if (r < 1 || tokens[0].type != JSMN_OBJECT) {
        return; // Invalid JSON
    }

    // Parse through all tokens
    for (int i = 1; i < r; i++) {
        // Check for single servo command
        if (jsoneq(json_string, &tokens[i], "servo") == 0) {
            // Look for servo number
            i++;
            int servo_id = extract_int(json_string, &tokens[i]);

            // Look for "angle" field
            i++;
            if (jsoneq(json_string, &tokens[i], "angle") == 0) {
                i++;
                int angle = extract_int(json_string, &tokens[i]);

                // Set servo angle
                PCA9685_SetSinglePwm(servo_id, AngleToPWM(angle));
                HAL_Delay(1);
            }
        }
        // Check for multiple servos array
        else if (jsoneq(json_string, &tokens[i], "servos") == 0) {
            // Next token should be array
            i++;
            if (tokens[i].type != JSMN_ARRAY) {
                continue;
            }

            int array_size = tokens[i].size;
            i++; // Move to first object in array

            // Process each servo object in array
            for (int j = 0; j < array_size; j++) {
                if (tokens[i].type != JSMN_OBJECT) {
                    break;
                }

                int servo_id = -1;
                int angle = -1;

                // Parse servo object
                int obj_size = tokens[i].size;
                i++; // Move to first key in object

                for (int k = 0; k < obj_size * 2; k += 2) {
                    if (jsoneq(json_string, &tokens[i+k], "id") == 0) {
                        servo_id = extract_int(json_string, &tokens[i+k+1]);
                    }
                    else if (jsoneq(json_string, &tokens[i+k], "angle") == 0) {
                        angle = extract_int(json_string, &tokens[i+k+1]);
                    }
                }

                // If we got both id and angle, set the servo
                if (servo_id >= 0 && angle >= 0) {
                    PCA9685_SetSinglePwm(servo_id, AngleToPWM(angle));
                    HAL_Delay(1);
                }

                i += obj_size * 2; // Move to next object
            }
        }
    }
}

void ProcessJsonMessage(void) {
    // Only process if we have a valid-looking JSON (starts with { and ends with })
    if (rx_index > 2 && rx_buffer[0] == '{' && rx_buffer[rx_index-1] == '}') {
        ProcessServoCommand((char*)rx_buffer);
        display_message((char*)rx_buffer); // Keep existing display functionality
        HAL_GPIO_TogglePin(GPIOC, GPIO_PIN_13); // Toggle LED on PC13
    }

    // Reset for next message
    rx_index = 0;
    message_received = 0;
}
/* USER CODE END 0 */

/**
  * @brief  The application entry point.
  * @retval int
  */
int main(void)
{

  /* MCU Configuration--------------------------------------------------------*/

  /* Reset of all peripherals, Initializes the Flash interface and the Systick. */
  HAL_Init();

  /* Configure the system clock */
  SystemClock_Config();

  /* Initialize all configured peripherals */
  MX_GPIO_Init();
  MX_I2C1_Init();
  MX_USART1_UART_Init();
  MX_USART2_UART_Init();
  /* USER CODE BEGIN 2 */
  ssd1306_Init();
  //PCA9685_Init();
  display_menu_item("UDP");
  // Start UART reception in interrupt mode
  HAL_UART_Receive_IT(&huart1, &rx_data, 1);
  /* USER CODE END 2 */

  /* Infinite loop */
  /* USER CODE BEGIN WHILE */
  while (1)
  {
    /* USER CODE END WHILE */

    /* USER CODE BEGIN 3 */
	if (!in_debug_mode) {
	       rotary_read();
	}
	if (message_received && in_debug_mode) {
	       ProcessJsonMessage();
	}
  }
  /* USER CODE END 3 */
}

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
/* USER CODE BEGIN 4 */
void HAL_UART_RxCpltCallback(UART_HandleTypeDef *huart)
{
    if (huart->Instance == USART1) {
        if (rx_index < JSON_BUFFER_SIZE - 1) {
            rx_buffer[rx_index++] = rx_data;

            // Check for end of JSON message
            if (rx_data == '\n' || rx_data == '}') {
                rx_buffer[rx_index] = '\0';
                message_received = 1;
            }
        } else {
            rx_index = 0;
        }

        HAL_UART_Receive_IT(&huart1, &rx_data, 1);
    }
}

void send_uart_message(const char* message) {
    HAL_UART_Transmit(&huart1, (uint8_t*)message, strlen(message), 100);
}
/* USER CODE END 4 */
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


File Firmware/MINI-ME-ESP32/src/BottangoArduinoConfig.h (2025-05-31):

#ifndef DevConsts_h
#define DevConsts_h

#include "BottangoArduinoModules.h"
#include <Arduino.h>

// !! Max Registered Motors !!
// Max effectors (motors, etc.) that can be registered at once.
// more than 8 crashes an Arduino Uno / Nano
// otherwise capped by default at 16, but can be increased if needed (depending on your hardware)

#if defined(ARDUINO_AVR_UNO) || defined(ARDUINO_AVR_NANO)
#ifdef USE_ADAFRUIT_PWM_LIBRARY
#define MAX_REGISTERED_EFFECTORS 6 // Arduino Uno or Nano + PCA driver can only support 6
#else
#define MAX_REGISTERED_EFFECTORS 8 // Arduino Uno or Nano bare pin pwm supports 8
#endif
#else
#define MAX_REGISTERED_EFFECTORS 18 // most modern boards can handle 16 or more (EX, ESP32, etc.)
#endif

// ---------------------------------- //

// !! Module Configuration !!

// !! Wifi Configuration !!
#ifdef USE_ESP32_WIFI
#define WIFI_SSID "A118_IWT_TEMPORARY"                   // wifi ssid
#define WIFI_PASSWORD "VIVES_ELOICT"               // wifi password
#define WIFI_SERVER_IP "10.198.112.11"              // wifi server ip on the local network, likely something like 192.168.1.X
#define WIFI_SERVER_PORT 59225                      // wifi server port on the local network
#endif

// !! Module Pins Configuration !!

// !! SD Card Pin Configuration !!
// Note that Arduino Uno / Nano are not supported with SD Card
#if defined(USE_SD_CARD_COMMAND_STREAM) || defined(AUDIO_SD_I2S)
#define SDPIN_CS 5                                  // chip select pin
#ifdef ESP32                                        // spi pins
#define SDPIN_MOSI 15                               // MOSI pin
#define SDPIN_CLK 18                                // clock pin
#define SDPIN_MISO 19                               // MISO pin
#endif
#endif

// !! Dynamic switch between live and exported animations !!
#ifdef ENABLE_DYNAMIC_ANIMATION_SOURCE_SWITCH
#define ANIMATION_STATE_SELECTION_PIN 13            // Pin to monitor on boot to determine if should be in live control or exported
#define SELECT_EXPORTED_IS_LOW                     // LOW on pin selects exported. Comment out this line to choose exported on highs.
#endif

// !! I2S and Audio Pins !!
#ifdef AUDIO_SD_I2S
#define I2S_BCLK 25                                 // bit clock line
#define I2S_LRC 17                                  // left right clock
#define I2S_DOUT 16                                 // data
#ifdef DYNAMIC_VOLUME
#define VOLUME_PIN 35
#define VOLUME_MIN 1.0;
#define VOLUME_MAX 0.01;
#endif
#ifdef PIN_ON_AUDIO_PLAY
#define AUDIO_ENABLE_PIN 2
#endif
#endif


// !! SD Card Pin Configuration !!
// Note that Arduino Uno / Nano are not supported with SD Card

// ---------------------------------- //

// !! The below are ADVANCED configurations !!

// Curve Evaluation:
// enable one of the bezier curve default evaluation methods:
//#define DEFAULT_FLOAT_CURVE // float math option (default, battle hardened and highly tested)
 #define DEFAULT_FIXED_CURVE                      // fixed math option. Slightly lower curve precision, but faster.  Likely will see improved HW communication and higher max effector count. New and being tested.


#define AVR_STEPPER_FIXED                           // in order to keep up with the demands of stepper motors, AVR boards (Arduino Uno, Nano, Mega, etc) use
                                                    // fixed evaluation overriding the above default. Comment this line out to use the default curve evaluation on avr steppers

#define VELOCITY_SEGMENT_MS 67                      // Velocity effectors (IE steppers) will segment curves into chunks of velocity. This field defines how long each chunk is in MS.
                                                    // lower number means more segments. More segments will be more accurate to the curve, but slower to process and less smooth stepper movement
                                                    // If you wanted to target 15 segments per second (the default) divide 1000 by 15: 1000 / 15 = 66.666, so rounded to 67
                                                    // 30 segments per second would be 33, etc.

#define STEPPER_SYNC_SPEED 2                        // steppers will sync at 1/X percent of max speed. IE, 2 == 50% max speed, 4 == 25% max Speed, etc.
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

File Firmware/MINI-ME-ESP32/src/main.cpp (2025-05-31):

#include "src/BottangoCore.h"
#include "src/BasicCommands.h"
#include <Wire.h>
#include "headers/ServoController.h"
#include "headers/UDPHandler.h"
#include "headers/WebConfig.h"
#include "headers/UartHandler.h"

// Add the I2C scanning function
void scanI2CDevices() {
  byte error, address;
  int deviceCount = 0;
  
  Serial.println("Scanning I2C bus...");
  
  for(address = 1; address < 127; address++) {
    Wire.beginTransmission(address);
    error = Wire.endTransmission();
    
    if (error == 0) {
      Serial.print("I2C device found at address 0x");
      if (address < 16) Serial.print("0");
      Serial.print(address, HEX);
      Serial.println();
      deviceCount++;
    } else if (error == 4) {
      Serial.print("Unknown error at address 0x");
      if (address < 16) Serial.print("0");
      Serial.println(address, HEX);
    }
  }
  
  if (deviceCount == 0) {
    Serial.println("No I2C devices found");
  } else {
    Serial.print("Found ");
    Serial.print(deviceCount);
    Serial.println(" device(s)");
  }
}

void setup()
{
  
  Serial.begin(115200); 
  Serial.println("Mini-me gestart");
  
  // Activeer de interne pull-up weerstanden
  pinMode(21, INPUT_PULLUP);
  pinMode(22, INPUT_PULLUP);
  
  // Initialize I2C with improved settings
  Wire.begin();
  Wire.setClock(400000); // Set I2C clock speed to 400kHz

  // Scan for connected I2C devices
  scanI2CDevices();
  
  // Add delay before accessing I2C devices
  delay(100);
  
  // Initialize servos
  setupServos();
  
  // Setup UART for mode switching
  setupUart();
  
  // Initialize WiFi
  setupWiFi();
  uint8_t mac[6];
  WiFi.macAddress(mac);
  
  char macStr[18] = {0};
  sprintf(macStr, "%02X:%02X:%02X:%02X:%02X:%02X", mac[0], mac[1], mac[2], mac[3], mac[4], mac[5]);
  Serial.print("Mac address: ");
  Serial.println(macStr);
  
  // Check if we're connected to a network
  if (!isInConfigMode()) {
      // If connected, start the UDP communication
      // Start in UDP mode by default
      setupUDP();
      stelModusIn(MODE_NORMAL);
  }
  
  // Initialize Bottango in the background so it's ready
  // but don't start it actively yet
  
  BottangoCore::bottangoSetup();
}

void loop()
{
  
  // Handle different modes with improved error handling
  if (isInConfigMode()) {
    // In config mode, handle the webserver for network connection
    handleWebClient();
  } 
  else {
    try {
      switch (getModus()) {
        case MODE_NORMAL:
          // Handle UDP packets in normal mode
          handleUDPPackets();
          break;
          
        case MODE_BOTTANGO:
        case MODE_ANIMATION:
          // Bottango or Animation mode
          BottangoCore::bottangoLoop();
          break;
      }
    } catch(...) {
      // Error recovery - if any mode crashes, fall back to UDP mode
      Serial.println("Error in loop() - switching to UDP mode");
      stelModusIn(MODE_NORMAL);
      if (BottangoCore::initialized) {
        BottangoCore::stop();
      }
      setupUDP();
      delay(100); // Give system time to stabilize
    }
  }
    
    
   //BottangoCore::bottangoLoop();
}

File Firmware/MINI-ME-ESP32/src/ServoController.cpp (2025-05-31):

#include "headers/ServoController.h"

Adafruit_PWMServoDriver mainBoard = Adafruit_PWMServoDriver(MAIN_BOARD_ADDR);
Adafruit_PWMServoDriver secondBoard = Adafruit_PWMServoDriver(SECOND_BOARD_ADDR);

// Initialiseer de servo's
void setupServos() {
    mainBoard.begin();
    mainBoard.setOscillatorFrequency(27000000); // Interne frequentie van de PCA9685
    mainBoard.setPWMFreq(SERVO_FREQ); // Frequentie van de PWM signalen voor de servo's
    
    secondBoard.begin();
    secondBoard.setOscillatorFrequency(27000000);
    secondBoard.setPWMFreq(SERVO_FREQ);
}

 // Zet de hoek van een servo in
void setServoAngle(uint8_t servo, uint8_t angle) {
    if(servo < NUM_SERVOS && angle <= 180) {
        // Bereken op welk board de servo zit en welk kanaal
        if (servo < MAIN_BOARD_CHANNELS) {
            // Servo zit op het hoofdboard
            mainBoard.setPWM(servo, 0, angleToPulse(angle));
            Serial.printf("Servo %d (hoofdboard) ingesteld op %d graden\n", servo, angle);
        } else {
            // Servo zit op het tweede board
            // Bereken de juiste kanaalindex voor het tweede board
            uint8_t secondBoardChannel = servo - MAIN_BOARD_CHANNELS;
            secondBoard.setPWM(secondBoardChannel, 0, angleToPulse(angle));
            Serial.printf("Servo %d (tweede board, kanaal %d) ingesteld op %d graden\n", 
                           servo, secondBoardChannel, angle);
        }
    }
}

// Zet een hoek om naar een puls lengte
uint16_t angleToPulse(uint8_t angle) {
    return map(angle, 0, 180, SERVOMIN, SERVOMAX);
}

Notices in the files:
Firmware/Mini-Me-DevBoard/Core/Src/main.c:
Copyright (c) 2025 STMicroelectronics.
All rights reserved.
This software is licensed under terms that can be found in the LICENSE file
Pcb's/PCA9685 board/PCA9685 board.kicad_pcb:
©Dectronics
